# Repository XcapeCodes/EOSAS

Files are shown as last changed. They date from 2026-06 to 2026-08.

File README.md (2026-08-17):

# EOSAS - Embedded Optical Skin Analysis System

EOSAS is an embedded imaging prototype developed to explore hardware/software integration, computer vision, and machine learning.

The system combines an ESP32-CAM for image acquisition, a Particle Argon for physical controls and system status, a custom dual-MCU PCB, C/C++ firmware, and a Python-based Flask/OpenCV/TensorFlow processing pipeline.

> **Note:** EOSAS is an educational engineering prototype. It is not a medical device and is not intended for diagnosis, treatment, or clinical use.

## Overview

EOSAS captures skin images using an ESP32-CAM, processes them through a machine learning pipeline, and displays results through a custom Flask dashboard. A Particle Argon controls the user interface, including scan lighting, button controls, and hazard indication LEDs.

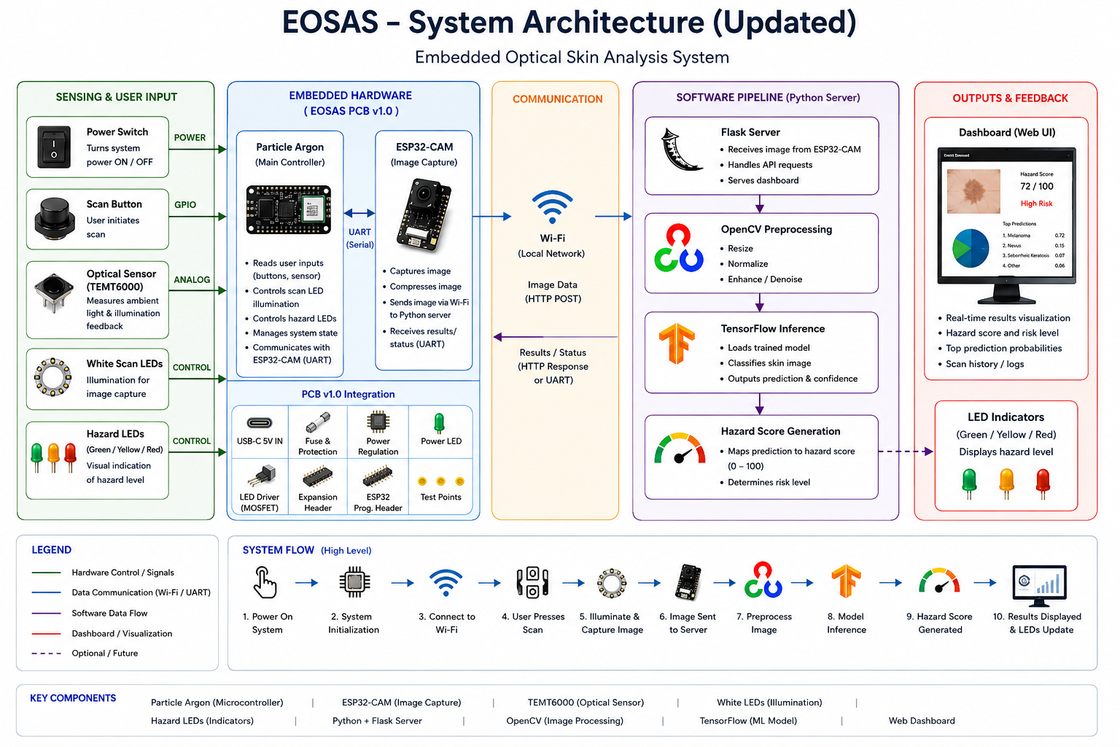
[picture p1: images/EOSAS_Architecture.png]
EOSAS Architecture

*Figure 1. High-level EOSAS system architecture showing embedded hardware, communication, machine learning pipeline, and dashboard outputs.*

## 🎥 Demo Video

A demonstration of the current EOSAS prototype can be found in the `demo` folder:

➡️ **eosas_demo.mov**

If GitHub does not preview the video directly, download the file to view the full demonstration.

## Project Status

### Completed
- Breadboard-based functional prototype
- ESP32-CAM image acquisition
- Particle Argon control firmware
- Flask dashboard and inference pipeline
- Custom PCB schematic and layout
- ERC/DRC verification

### In Progress
- PCB fabrication and bring-up
- Hardware validation
- Optical sensor calibration
- Custom enclosure

### Planned
- PCB revision based on bring-up results
- Battery-powered operation
- Improved wireless reliability
- Additional model/data evaluation

## Custom PCB

EOSAS PCB v1.0 is a custom dual-MCU carrier board designed to replace the breadboard wiring used in the original prototype and consolidate the system electronics onto a dedicated PCB.

The board integrates:
- Particle Argon and ESP32-CAM
- USB-C power input and protection
- Optical sensing
- Controlled scan illumination
- Low / Medium / High hazard indicators
- Power and scan controls
- Programming, expansion, and debugging interfaces

**Status:** Design complete; fabrication and physical validation pending.

Full PCB design files, schematic, layout, and documentation are available in the [`PCB/`](PCB/) directory.

## Features

* ESP32-CAM image capture
* Machine learning image classification
* Flask-based AI server
* Real-time dashboard visualization
* Particle Argon hardware controller
* White illumination LEDs
* Hazard indication LEDs (Green / Yellow / Red)
* Wi-Fi setup portal
* SD card image logging
* Portable multi-network deployment

## Hardware

- ESP32-CAM with OV2640 camera
- Particle Argon
- EOSAS PCB v1.0
- TEMT6000 optical light sensor
- White scan illumination
- Low / Medium / High hazard LEDs
- Scan push button
- Power switch
- USB-C 5 V power input
- External illumination connector
- ESP32 programming header
- Expansion/debug header
- SD card storage
  
## Software

* Python
* Flask
* TensorFlow / Keras
* OpenCV
* C++
* Arduino Framework
* Particle Device OS

## System Workflow

1. User powers on EOSAS
2. Particle Argon initializes the hardware
3. ESP32-CAM connects to the configured network
4. EOSAS locates the inference server
5. User positions the target skin area
6. User presses the Scan button
7. Optical sensor measures illumination conditions
8. White scan lighting is activated
9. ESP32-CAM captures the image
10. Image is sent to the Python inference server
11. OpenCV preprocesses the image
12. TensorFlow generates the hazard prediction
13. Hazard score and confidence are calculated
14. Results are displayed on the dashboard
15. EOSAS updates the Low / Medium / High hazard indicator LED

## Engineering Decisions & Tradeoffs

### Dual-MCU Architecture
The Particle Argon manages physical user controls, illumination, and status indicators, while the ESP32-CAM handles image acquisition and network communication. This separates hardware-control responsibilities from camera and image-transfer tasks.

### Custom PCB
PCB v1.0 consolidates the original breadboard wiring into a dedicated carrier board with USB-C power/protection, optical sensing, illumination control, status indicators, and programming/debug interfaces.

### Controlled Illumination
White scan LEDs and an optical light sensor are included to support more consistent image-capture conditions and future calibration work.

### Debug and Expansion Access
Programming and debug interfaces were included to simplify board bring-up, firmware development, and future hardware revisions.

## Future Improvements

- Fabricate and validate EOSAS PCB v1.0
- Complete optical sensor calibration
- Build PCB-based custom enclosure
- Add battery-powered operation
- Improve hazard scoring
- Expand training data with EOSAS-captured images
- Improve condition-matching model
- Add automatic server discovery
- Improve wireless communication reliability

## Repository Structure

```text
EOSAS/
├── Firmware/   Embedded firmware and device control
├── PCB/        KiCad schematic, layout, renders, and documentation
├── Software/   Flask/OpenCV/TensorFlow application code
├── models/     Machine-learning models and related files
├── demo/       Prototype demonstration
└── images/     Architecture diagrams and project media
```

## Third-Party

Portions of the ESP32 camera-server implementation are based on Espressif reference/example code and remain subject to their respective licensing terms.

EOSAS-specific hardware design, system integration, control firmware, software, and modifications are documented separately within this repository.

## Author

Mishael Agbali

Electrical Engineering Student
University of South Florida

LinkedIn:
https://www.linkedin.com/in/mishael-agbali/

GitHub:
https://github.com/XcapeCodes

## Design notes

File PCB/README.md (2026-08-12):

[← Back to main EOSAS documentation](../README.md)
# EOSAS PCB v1.0

EOSAS PCB v1.0 is a custom dual-MCU carrier board designed to replace the breadboard wiring used in the original EOSAS prototype and consolidate the system electronics onto a dedicated PCB.

## Current Status

**Design complete — fabrication and physical validation pending.**

- Schematic completed
- PCB routing completed
- ERC passed
- DRC passed
- Ground plane completed
- Silkscreen and module outlines added
- 3D board layout reviewed

## PCB Features

- Particle Argon and ESP32-CAM integration
- USB-C 5 V power input
- Input fuse and power control
- Power status indicator
- TEMT6000 optical sensor interface
- MOSFET-controlled white scan illumination
- Low / Medium / High hazard indicator LEDs
- Separate power and scan controls
- ESP32 programming header
- Expansion interface
- External illumination connector
- Debug test points
- ESP32-CAM bulk capacitance for power stability
- Four mounting points for enclosure integration

## Design

### Schematic

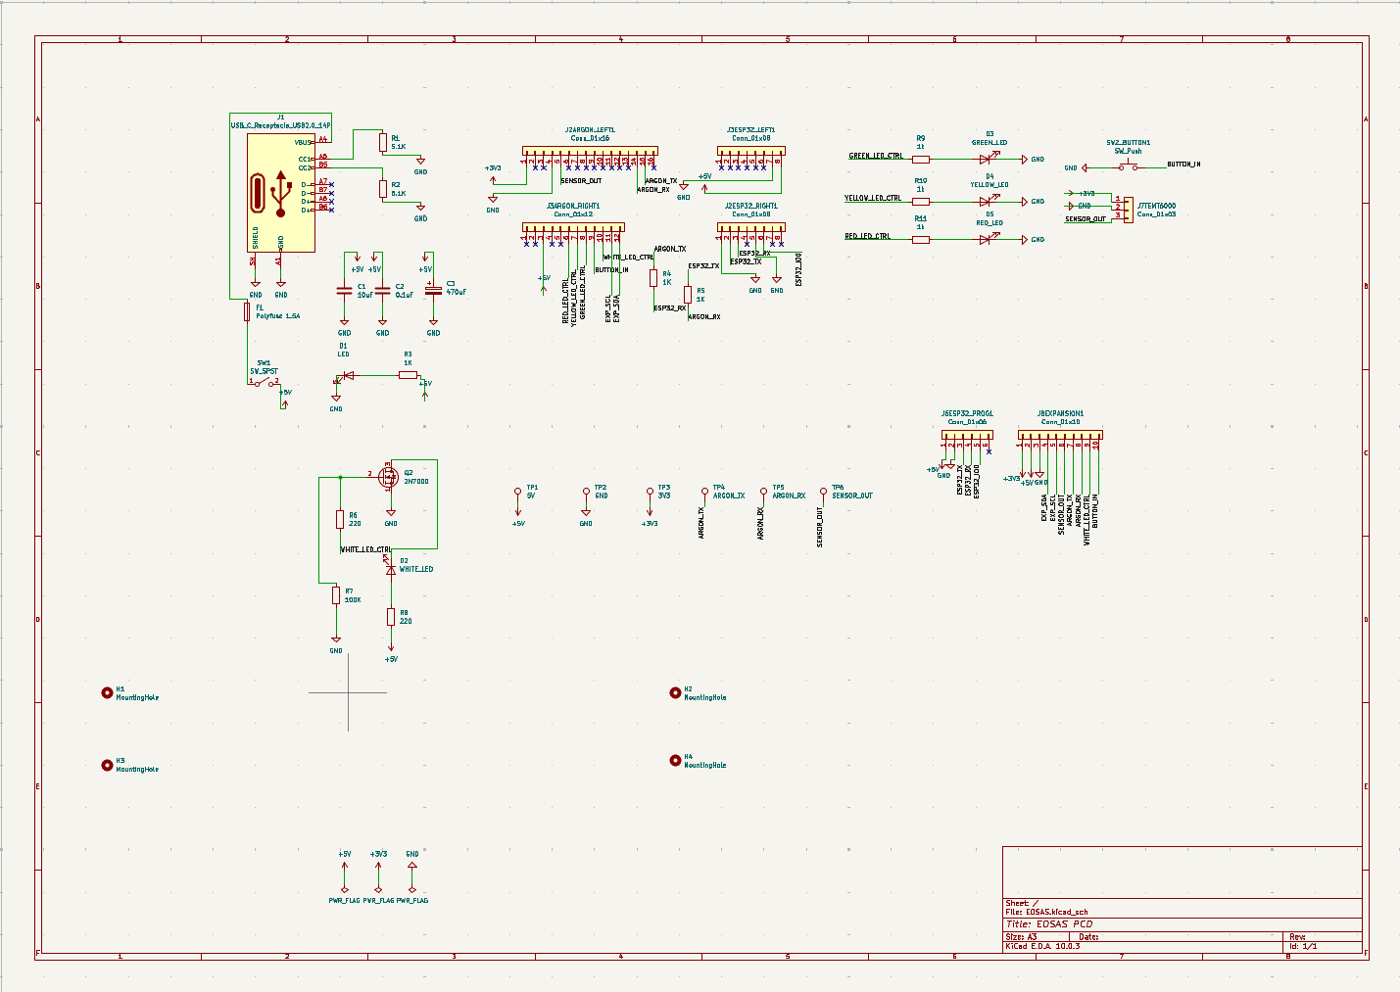
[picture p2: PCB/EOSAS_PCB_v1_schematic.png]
EOSAS PCB v1.0 Schematic


### PCB Layout

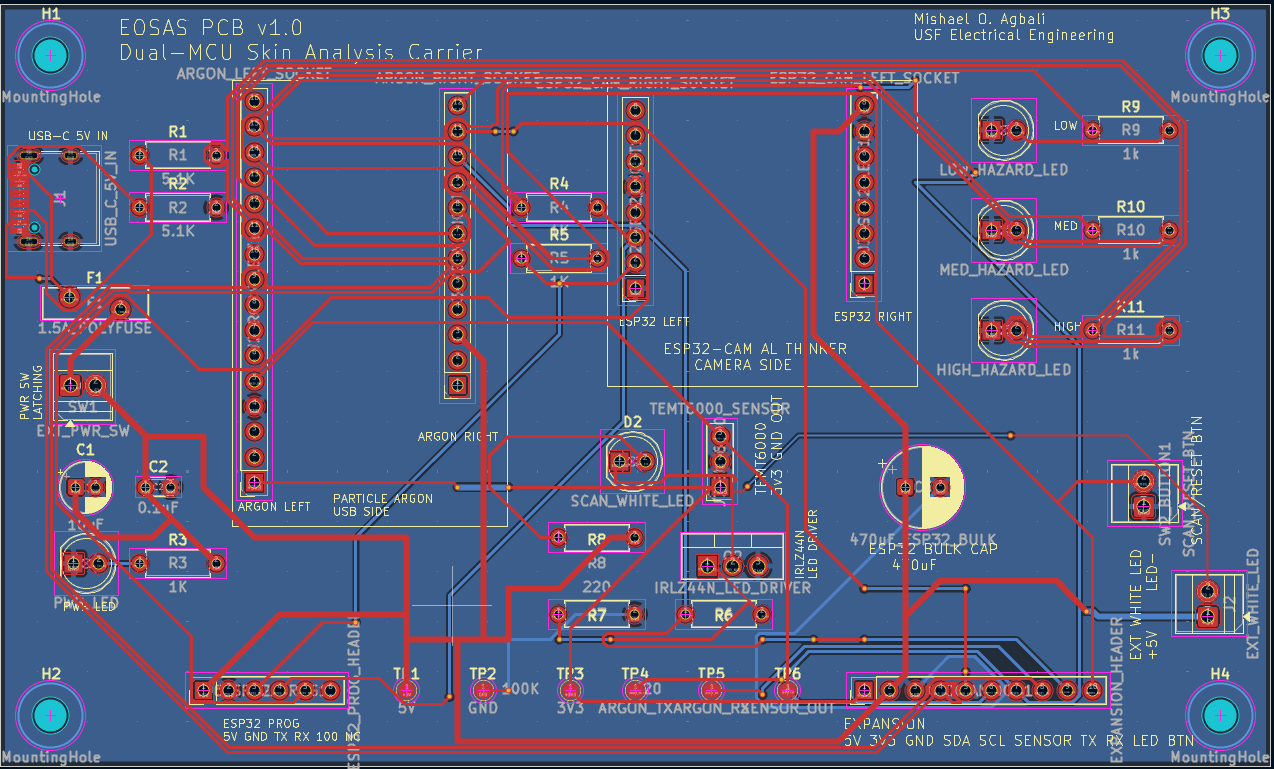
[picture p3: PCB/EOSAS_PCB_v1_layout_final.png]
EOSAS PCB v1.0 Layout


### 3D Render
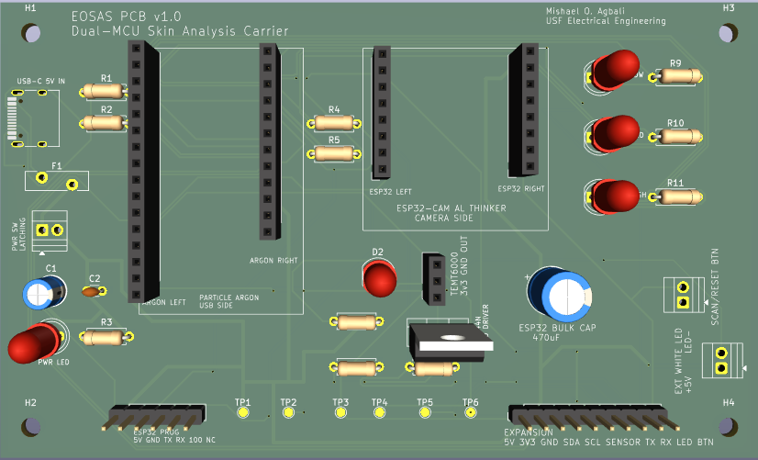
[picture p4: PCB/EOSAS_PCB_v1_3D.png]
EOSAS PCB v1.0 3D Render


## Architecture

The Particle Argon serves as the primary hardware controller, managing user inputs, illumination, optical sensing, and hazard indicators. The ESP32-CAM handles image acquisition and communication with the EOSAS inference server.

The two controllers communicate through the PCB's dedicated interface, allowing the embedded hardware and image-processing pipeline to operate as one system.

## Next Steps

- Complete final pre-fabrication review
- Generate manufacturing files
- Fabricate PCB v1.0
- Assemble and perform board bring-up
- Validate power rails and interfaces
- Test Argon-to-ESP32 communication
- Calibrate optical sensing and scan illumination
- Integrate PCB into the final EOSAS enclosure
- Complete full system validation

> EOSAS is an experimental engineering project and is not intended to provide medical diagnoses.

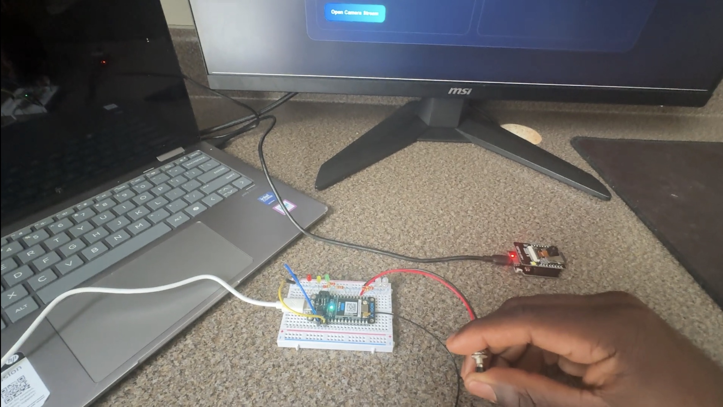
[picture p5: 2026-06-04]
images/eosas_hardware_overview.JPG

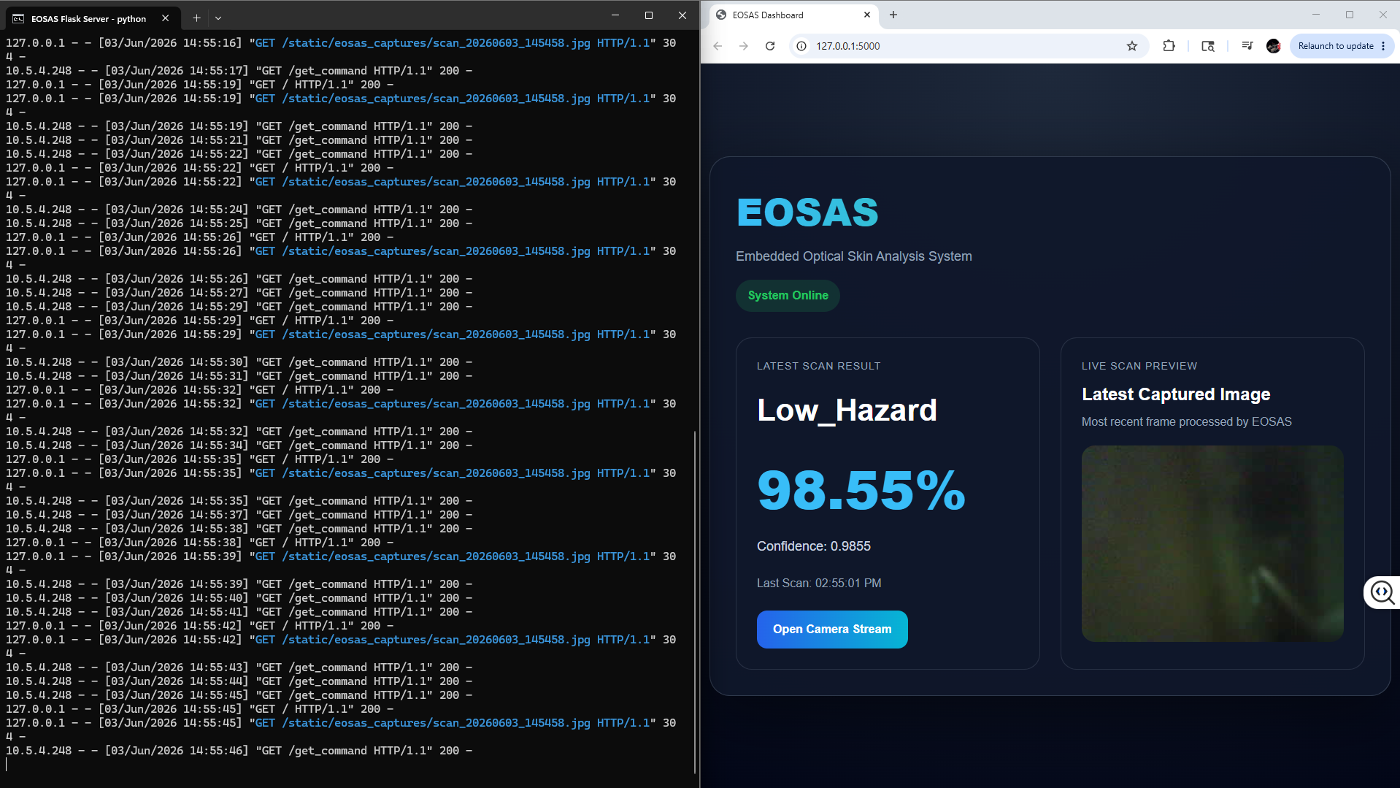
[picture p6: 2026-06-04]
images/dashboard.png

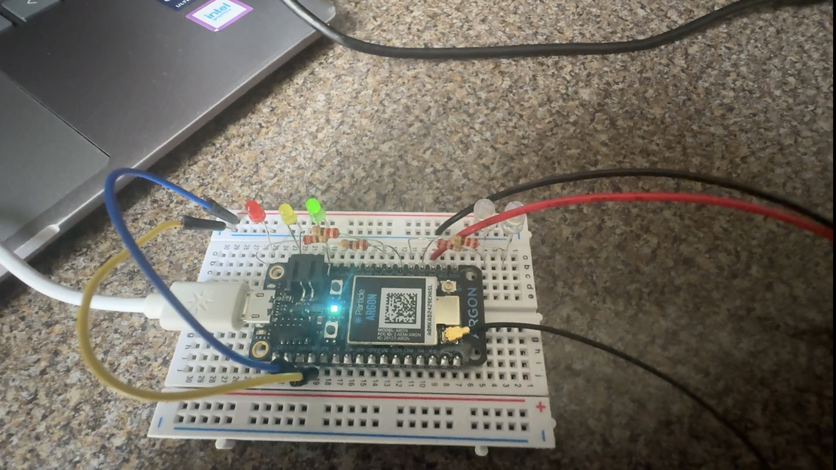
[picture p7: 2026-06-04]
images/eosas_argon_closeup.jpg.JPG

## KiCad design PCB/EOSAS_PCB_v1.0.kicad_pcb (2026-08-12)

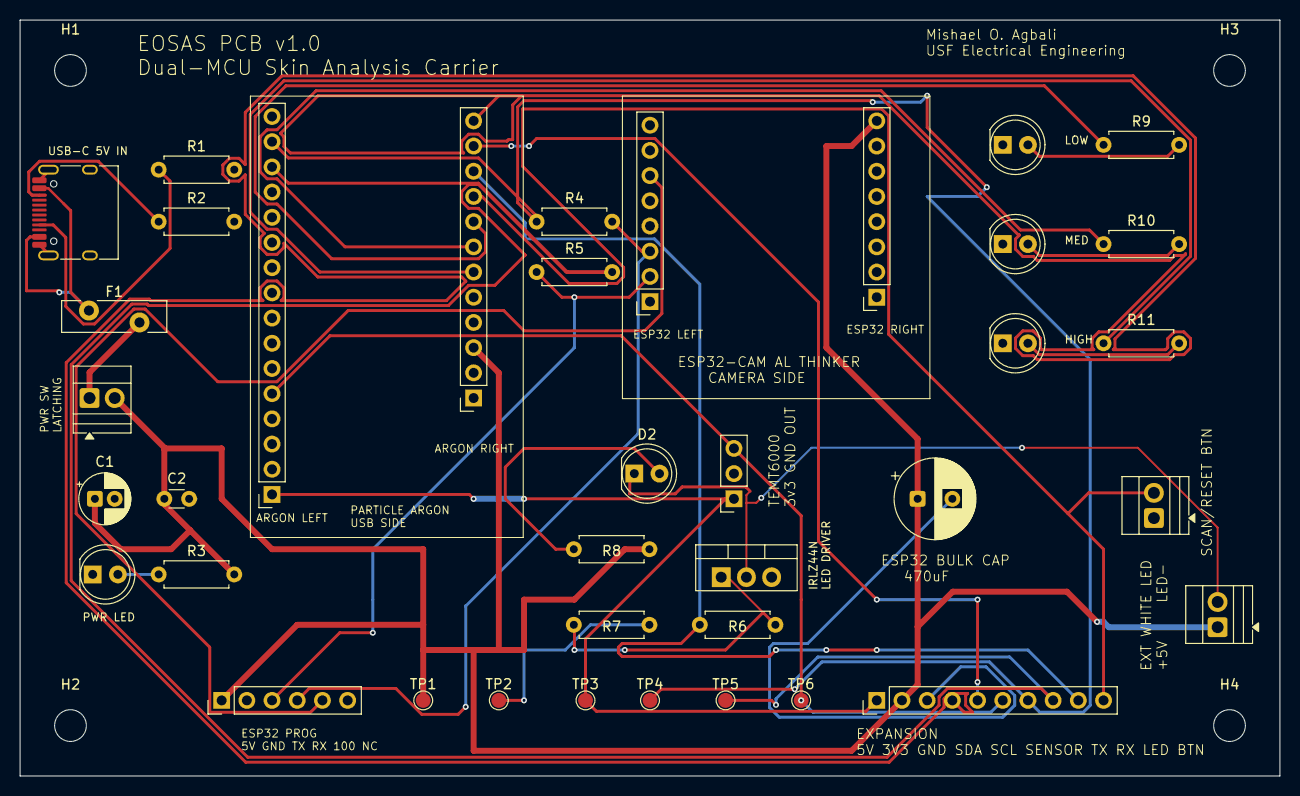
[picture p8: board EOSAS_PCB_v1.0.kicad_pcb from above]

Board: 2 copper layers, 127.0 x 76.2 mm, 42 parts (0 on the bottom side), 27 nets.

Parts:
C1: 10uF; CP_Radial_D5.0mm_P2.00mm
C2: 0.1uF; C_Disc_D3.0mm_W1.6mm_P2.50mm
C3: 470uF_ESP32_BULK; CP_Radial_D8.0mm_P3.50mm
D1: PWR_LED; LED_D5.0mm
D2: SCAN_WHITE_LED; LED_D5.0mm
D3: LOW_HAZARD_LED; LED_D5.0mm
D4: MED_HAZARD_LED; LED_D5.0mm
D5: HIGH_HAZARD_LED; LED_D5.0mm
F1: 1.5A_POLYFUSE; Fuse_Bourns_MF-RG500
H1, H2, H3, H4: MountingHole; MountingHole_3.2mm_M3
J1: USB_C_5V_IN; USB_C_Receptacle_HRO_TYPE-C-31-M-12
J2: EXT_WHITE_LED; TerminalBlock_Xinya_XY308-2.54-2P_1x02_P2.54mm_Horizontal
J2ARGON_LEFT1: ARGON_LEFT_SOCKET; PinSocket_1x16_P2.54mm_Vertical
J2ESP32_RIGHT1: ESP32_CAM_RIGHT_SOCKET; PinSocket_1x08_P2.54mm_Vertical
J3ARGON_RIGHT1: ARGON_RIGHT_SOCKET; PinSocket_1x12_P2.54mm_Vertical
J3ESP32_LEFT1: ESP32_CAM_LEFT_SOCKET; PinSocket_1x08_P2.54mm_Vertical
J6ESP32_PROG1: ESP32_PROG_HEADER; PinHeader_1x06_P2.54mm_Vertical
J7TEMT6000: TEMT6000_SENSOR; PinSocket_1x03_P2.54mm_Vertical
J8EXPANSION1: EXPANSION_HEADER; PinHeader_1x10_P2.54mm_Vertical
Q2: IRLZ44N_LED_DRIVER; TO-220-3_Vertical
R1, R2: 5.1K; R_Axial_DIN0207_L6.3mm_D2.5mm_P7.62mm_Horizontal
R3, R4, R5: 1K; R_Axial_DIN0207_L6.3mm_D2.5mm_P7.62mm_Horizontal
R6, R8: 220; R_Axial_DIN0207_L6.3mm_D2.5mm_P7.62mm_Horizontal
R7: 100K; R_Axial_DIN0207_L6.3mm_D2.5mm_P7.62mm_Horizontal
R9, R10, R11: 1k; R_Axial_DIN0207_L6.3mm_D2.5mm_P7.62mm_Horizontal
SW1: EXT_PWR_SW; TerminalBlock_Xinya_XY308-2.54-2P_1x02_P2.54mm_Horizontal
SW2_BUTTON1: SCAN_RESET_BTN; TerminalBlock_Xinya_XY308-2.54-2P_1x02_P2.54mm_Horizontal
TP1: 5V; TestPoint_Pad_D1.5mm
TP2: GND; TestPoint_Pad_D1.5mm
TP3: 3V3; TestPoint_Pad_D1.5mm
TP4: ARGON_TX; TestPoint_Pad_D1.5mm
TP5: ARGON_RX; TestPoint_Pad_D1.5mm
TP6: SENSOR_OUT; TestPoint_Pad_D1.5mm

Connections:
+3V3: J2ARGON_LEFT1.1, J7TEMT6000.1, J8EXPANSION1.1, TP3.1 (1_1)
+5V: C1.1, C2.1, C3.1, J2.1, J3ARGON_RIGHT1.3, J3ESP32_LEFT1.8, J6ESP32_PROG1.1, J8EXPANSION1.2, R3.2, R8.2, SW1.2 (B), TP1.1 (1_1)
/ARGON_RX: J2ARGON_LEFT1.14, J8EXPANSION1.8, R5.2, TP5.1 (1_1)
/ARGON_TX: J2ARGON_LEFT1.15, J8EXPANSION1.7, R4.1, TP4.1 (1_1)
/BUTTON_IN: J3ARGON_RIGHT1.9, J8EXPANSION1.10, SW2_BUTTON1.2
/ESP32_IO0: J2ESP32_RIGHT1.6, J6ESP32_PROG1.5
/ESP32_RX: J2ESP32_RIGHT1.3, J6ESP32_PROG1.4, R4.2
/ESP32_TX: J2ESP32_RIGHT1.2, J6ESP32_PROG1.3, R5.1
/EXP_SCL: J3ARGON_RIGHT1.11, J8EXPANSION1.5
/EXP_SDA: J3ARGON_RIGHT1.12, J8EXPANSION1.4
/GREEN_LED_CTRL: J3ARGON_RIGHT1.8, R9.1
/LED_NEG: D2.1 (K), J2.2, Q2.2 (D)
/RED_LED_CTRL: J3ARGON_RIGHT1.6, R11.1
/SENSOR_OUT: J2ARGON_LEFT1.5, J7TEMT6000.3, J8EXPANSION1.6, TP6.1 (1_1)
/WHITE_LED_CTRL: J3ARGON_RIGHT1.10, J8EXPANSION1.9, R6.1
/YELLOW_LED_CTRL: J3ARGON_RIGHT1.7, R10.1
GND: C1.2, C2.2, C3.2, D1.1 (K), D3.1 (K), D4.1 (K), D5.1 (K), J1.A1 (GND), J1.A12 (GND), J1.B1 (GND), J1.B12 (GND), J1.SH (SHIELD), J2ARGON_LEFT1.4, J2ESP32_RIGHT1.1, J2ESP32_RIGHT1.5, J3ESP32_LEFT1.7, J6ESP32_PROG1.2, J7TEMT6000.2, J8EXPANSION1.3, Q2.3 (S), R1.2, R2.2, R7.2, SW2_BUTTON1.1, TP2.1 (1_1)
unnamed: D1.2 (A), R3.1
unnamed: D2.2 (A), R8.1
unnamed: D3.2 (A), R9.2
unnamed: D4.2 (A), R10.2
unnamed: D5.2 (A), R11.2
unnamed: F1.1, J1.A4 (VBUS), J1.A9 (VBUS), J1.B4 (VBUS), J1.B9 (VBUS)
unnamed: J1.A5 (CC1), R1.1
unnamed: J1.B5 (CC2), R2.1
unnamed: Q2.1 (G), R6.2, R7.1
unnamed: F1.2, SW1.1 (A)

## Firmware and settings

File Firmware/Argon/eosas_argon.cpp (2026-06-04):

// ==========================
// EOSAS ARGON HARDWARE CONTROLLER
// Particle Argon - Web IDE Compatible
// ==========================

TCPClient client;

// ==========================
// SERVER SETTINGS
// ==========================

// Default Flask server IP.
// You can update this without reflashing by using Particle Console function:
// Function name: setServerIP
// Argument example: 192.168.1.39
char SERVER_IP[32] = "192.168.1.39";

const int SERVER_PORT = 5000;

// ==========================
// PIN DEFINITIONS
// ==========================

const int BUTTON_PIN = D2;

const int WHITE_LED_LEFT = D3;
const int WHITE_LED_RIGHT = D4;

const int GREEN_LED = D5;
const int YELLOW_LED = D6;
const int RED_LED = D7;

// ==========================
// BUTTON CLICK SETTINGS
// ==========================

unsigned long lastClickTime = 0;
int clickCount = 0;

const unsigned long DOUBLE_CLICK_TIME = 500;

// ==========================
// FUNCTION DECLARATIONS
// ==========================

void startEOSASScan();
void resetSystem();
void allOff();
void allResultLightsOff();
String sendGET(String path);
int setServerIP(String newIP);

// ==========================
// SETUP
// ==========================

void setup() {
    Serial.begin(9600);

    // Allows IP update from Particle Console without reflashing
    Particle.function("setServerIP", setServerIP);

    pinMode(BUTTON_PIN, INPUT_PULLUP);

    pinMode(WHITE_LED_LEFT, OUTPUT);
    pinMode(WHITE_LED_RIGHT, OUTPUT);

    pinMode(GREEN_LED, OUTPUT);
    pinMode(YELLOW_LED, OUTPUT);
    pinMode(RED_LED, OUTPUT);

    allOff();

    Serial.println("=================================");
    Serial.println("EOSAS Argon Hardware Controller");
    Serial.println("Ready");
    Serial.print("Current Flask Server IP: ");
    Serial.println(SERVER_IP);
    Serial.println("=================================");
}

// ==========================
// LOOP
// ==========================

void loop() {

    // Detect button press
    if (digitalRead(BUTTON_PIN) == LOW) {

        clickCount++;
        lastClickTime = millis();

        // Wait until button is released
        while (digitalRead(BUTTON_PIN) == LOW) {
            delay(10);
        }

        // Debounce
        delay(50);
    }

    // Decide single click vs double click
    if (clickCount > 0 && millis() - lastClickTime > DOUBLE_CLICK_TIME) {

        if (clickCount == 1) {
            startEOSASScan();
        }
        else {
            resetSystem();
        }

        clickCount = 0;
    }
}

// ==========================
// MAIN EOSAS SCAN FLOW
// ==========================

void startEOSASScan() {
    Serial.println();
    Serial.println("Single click detected.");
    Serial.println("Starting EOSAS scan...");

    allOff();

    // Turn on scan lighting
    digitalWrite(WHITE_LED_LEFT, HIGH);
    digitalWrite(WHITE_LED_RIGHT, HIGH);

    Serial.println("White LEDs ON.");

    // Tell Flask that a scan is requested
    String startResponse = sendGET("/start_scan");

    Serial.println("Start scan response:");
    Serial.println(startResponse);

    // Keep lighting on while ESP32 captures/uploads
    delay(7000);

    // Turn off scan lighting
    digitalWrite(WHITE_LED_LEFT, LOW);
    digitalWrite(WHITE_LED_RIGHT, LOW);

    Serial.println("White LEDs OFF.");

    // Get latest AI result
    String result = sendGET("/latest_result");

    Serial.println("Latest result response:");
    Serial.println(result);

    allResultLightsOff();

    // Choose LED based on class result
    if (result.indexOf("Low_Hazard") >= 0 ||
        result.indexOf("low_hazard") >= 0 ||
        result.indexOf("Low") >= 0 ||
        result.indexOf("low") >= 0) {

        Serial.println("LED RESULT: GREEN / LOW HAZARD");
        digitalWrite(GREEN_LED, HIGH);
    }
    else if (result.indexOf("Medium_Hazard") >= 0 ||
             result.indexOf("medium_hazard") >= 0 ||
             result.indexOf("Medium") >= 0 ||
             result.indexOf("medium") >= 0) {

        Serial.println("LED RESULT: YELLOW / MEDIUM HAZARD");
        digitalWrite(YELLOW_LED, HIGH);
    }
    else if (result.indexOf("High_Hazard") >= 0 ||
             result.indexOf("high_hazard") >= 0 ||
             result.indexOf("High") >= 0 ||
             result.indexOf("high") >= 0) {

        Serial.println("LED RESULT: RED / HIGH HAZARD");
        digitalWrite(RED_LED, HIGH);
    }
    else {
        Serial.println("LED RESULT: UNKNOWN - DEFAULTING TO YELLOW");
        digitalWrite(YELLOW_LED, HIGH);
    }
}

// ==========================
// RESET SYSTEM
// ==========================

void resetSystem() {
    Serial.println();
    Serial.println("Double click detected.");
    Serial.println("Resetting EOSAS LEDs...");

    allOff();
}

// ==========================
// LED HELPERS
// ==========================

void allOff() {
    digitalWrite(WHITE_LED_LEFT, LOW);
    digitalWrite(WHITE_LED_RIGHT, LOW);

    digitalWrite(GREEN_LED, LOW);
    digitalWrite(YELLOW_LED, LOW);
    digitalWrite(RED_LED, LOW);
}

void allResultLightsOff() {
    digitalWrite(GREEN_LED, LOW);
    digitalWrite(YELLOW_LED, LOW);
    digitalWrite(RED_LED, LOW);
}

// ==========================
// HTTP GET REQUEST HELPER
// ==========================

String sendGET(String path) {
    String response = "";

    Serial.print("Connecting to Flask server at ");
    Serial.print(SERVER_IP);
    Serial.print(":");
    Serial.println(SERVER_PORT);

    if (client.connect(SERVER_IP, SERVER_PORT)) {

        client.println("GET " + path + " HTTP/1.1");
        client.println("Host: " + String(SERVER_IP));
        client.println("Connection: close");
        client.println();

        unsigned long timeout = millis();

        while (client.connected() && millis() - timeout < 5000) {
            while (client.available()) {
                char c = client.read();
                response += c;
            }
        }

        client.stop();
    }
    else {
        Serial.println("Connection to Flask failed.");
    }

    return response;
}

// ==========================
// PARTICLE CLOUD FUNCTION
// UPDATE SERVER IP WITHOUT REFLASHING
// ==========================

int setServerIP(String newIP) {

    if (newIP.length() == 0 || newIP.length() >= sizeof(SERVER_IP)) {
        Serial.println("Invalid IP received.");
        return -1;
    }

    newIP.toCharArray(SERVER_IP, sizeof(SERVER_IP));

    Serial.println();
    Serial.print("New Flask Server IP set to: ");
    Serial.println(SERVER_IP);

    return 1;
}

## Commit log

2026-08-12 PCB pre-fabrication
2026-08-12 PCB Design
2026-08-12 Source code
    [EOSAS_PCB_v1.0.kicad_pcb.kicad_pcb, EOSAS_PCB_v1.0.kicad_sch.kicad_sch]
